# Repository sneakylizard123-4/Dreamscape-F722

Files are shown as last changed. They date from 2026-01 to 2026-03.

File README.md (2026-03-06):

# Dreamscape F722
Dreamscape F722 is an open-hardware STM32-based flight controller designed for FPV and custom drone platforms. It targets high-performance firmware such as Betaflight, iNav, and ArduPilot while remaining developer-friendly for experimentation and customization. The design focuses on a powerful MCU, robust connectivity, and support for a wide range of peripherals to enable advanced flight control features and future expansion.

# Features
## MCU
- STM32 F722RET6
- 32-bit ARM Cortex-M7 CPU
- Up to 216 MHz clock speed
- Large memory for advanced firmware features
- Compatible with Betaflight/iNav/ArduPilot

## Power System
- 5V input with built-in 3.3v regulator
- Power distribution for peripherals
- USB Power support
- Protection for USB

## Connectivity
- USB Type-C for programming and communication
- Multiple UART ports for telemetry and peripherals
- I2C bus for sensors and accessories
- SPI interface for high-speed communication
- SWD debugging port

## Sensors
- ICM-42688-P 6-axis IMU (3-axis gyroscope + 3-axis accelerometer) via SPI for precise flight control and low latency
- BMP280 barometer for altitude sensing
- Optional external sensor support via I2C

## Flight Control Outputs
- 8 PWM outputs
- Supports DSHOT, Oneshot, and standard PWM protocols
- Compatible with individual ESCs or 4-in-1 ESCs

## Radio / Receiver Support
- CRSF (Crossfire) support for long-range control
- SBUS support for standard RC receivers
- PPM support for legacy receivers
- Support for external radio modules via UART

## Status & Indicators
- Power LED
- User LED
- Boot/Status LED

## Expansion & Peripherals
- GPS module support via UART
- Telemetry Radios
- VTX control (SmartAudio or Tramp)
- Buzzer for audible alerts
- Camera control
- External sensor support (e.g., magnetometer, external barometer)

## Physical Design
- Compact flight-controller form factor (30x30mm)
- Standard mounting pattern
- Designed for custom drones

## Development Friendly
- Open-source hardware design files
- Open-source firmware support (Betaflight, iNav, ArduPilot)
- Easy debugging with SWD port

## Planned Future Features
- Integrated ELRS receiver
- Dual-Band telemetry support
- Advanced Sensor suite
- Power monitoring improvements
- Integrated OSD support

# Specifications
## Core Specifications
### MCU
- MCU: STM32 F722RET6
- Architecture: ARM Cortex-M7
- Clock Speed: Up to 216 MHz
- Flash Memory: 512 KB
- RAM: 256 KB
- Hardware Floating Point Unit (FPU)

### Inertial Measurement Unit (IMU)
- IMU: ICM-42688-P
- HIgh-speed SPI bus for low latency
- Optimied placement for reduced vibration noise

### Power System
- Input Voltage: 5V (via USB or power distribution)
- Built-in 3.3V regulator for peripherals
- USB Power support with protection
- Power distribution for connected peripherals

## I/O and Connectivity
### UART Ports
- UART1: Receiver 
- UART2: GPS module
- UART3: Telemetry
- UART4: VTX Control
- UART5: Reserved for future expansion

### SPI Interfaces
- SPI1: IMU (ICM-42688-P)
- SPI2: Reserved for future sensor expansion

### I2C Bus
- I2C bus available for peripherals such as magnetometers, external barometers, etc.

### SWD
- SWD header for debugging and firmware development

## Motor Outputs
- Up to 8 PWM outputs
- Suppored Protocols:
  - DShot150/300/600
  - OneShot
  - Multishot
  - Standard PWM
  - Compatible with individual ESCs or 4-in-1 ESCs

## Receiver Support
- CRSF (Crossfire) support for long-range control
- SBUS support for standard RC receivers
- PPM support for legacy receivers
- Support for external radio modules via UART

## Additional Peripherals
- Buzzer output
- LED Strip output
- Camera control
- VTX control (SmartAudio or Tramp)

## Status Indicators
- Power LED
- User LED
- Boot/Status LED

## Physical Dimensions
- Size: 30x30mm
- Board Layers: 4
- PCB Thickness: 1.6mm
- Copper Weight: 1oz
- Dimensions: Standard flight controller mounting pattern

## Firmware Compatibility
- Designed for compatibility with Betaflight, iNav, and ArduPilot
- Open-source firmware support for customization and development

## Development Features
- Open Hardware design
- Full SWD debugging support
- Compatible with ST-Link Programmers
- Designed for experimentation and customization

## Planned Future Features
- Integrated ELRS receiver for long-range control
- Dual-Band telemetry support for improved communication
- Advanced Sensor suite including magnetometer and external barometer support
- Integrated ESC for AIO support
- Integrated OSD support for on-screen display of flight information
- Improved powwer monitoring with current sensing and voltage monitoring

# Firmware Building
````bash
cd ~/Dreamscape-F722/firmware/betaflight/betaflight
make configs
make DREAMSCAPEF722
````

# Blender Render:
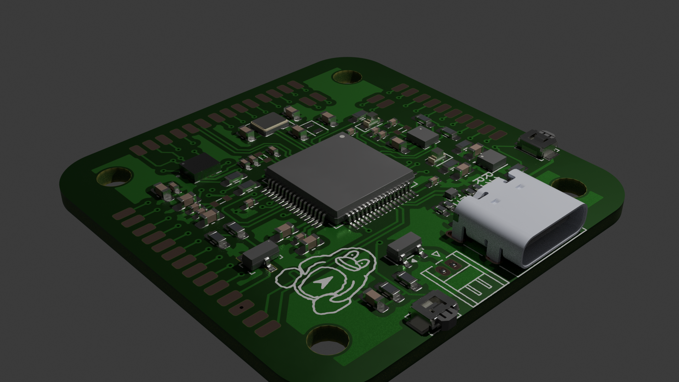
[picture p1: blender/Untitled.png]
BlenderRender

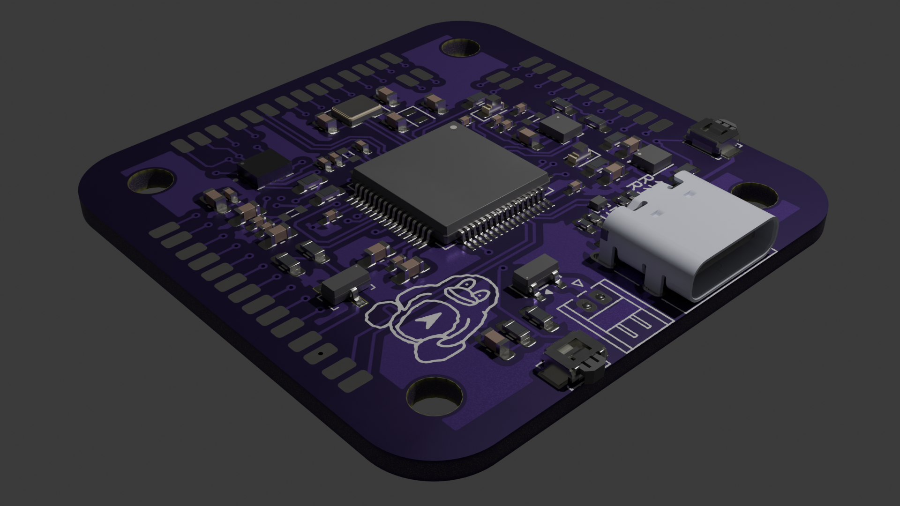
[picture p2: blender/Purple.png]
Purple


# Schematics & PCB view
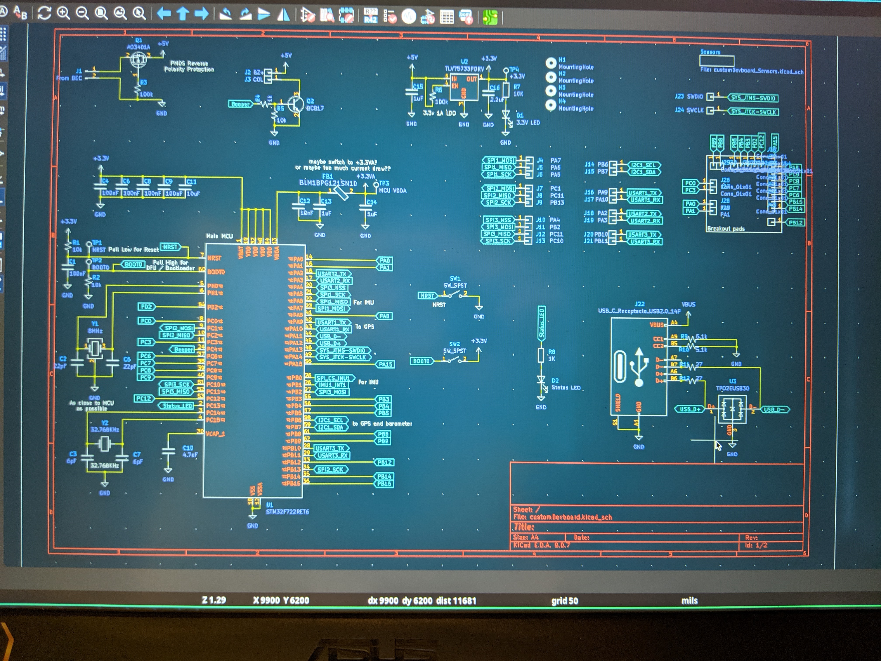
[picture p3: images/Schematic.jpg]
Schematic

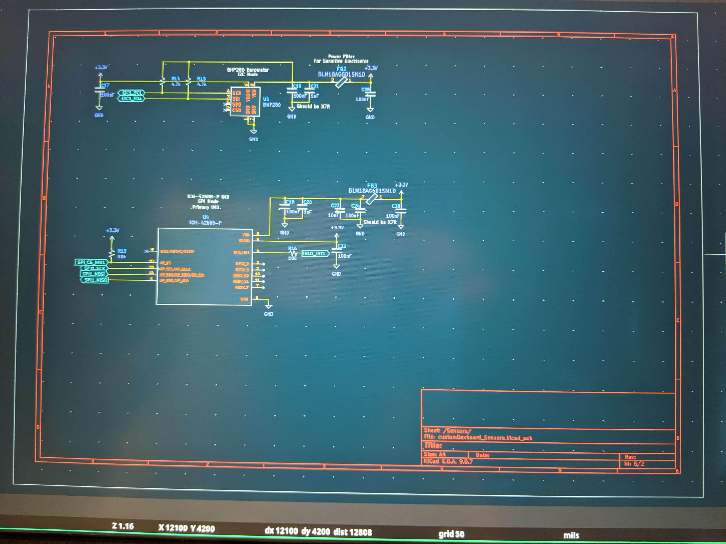
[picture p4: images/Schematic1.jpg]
Schematic1

PCB
PDF

# prices
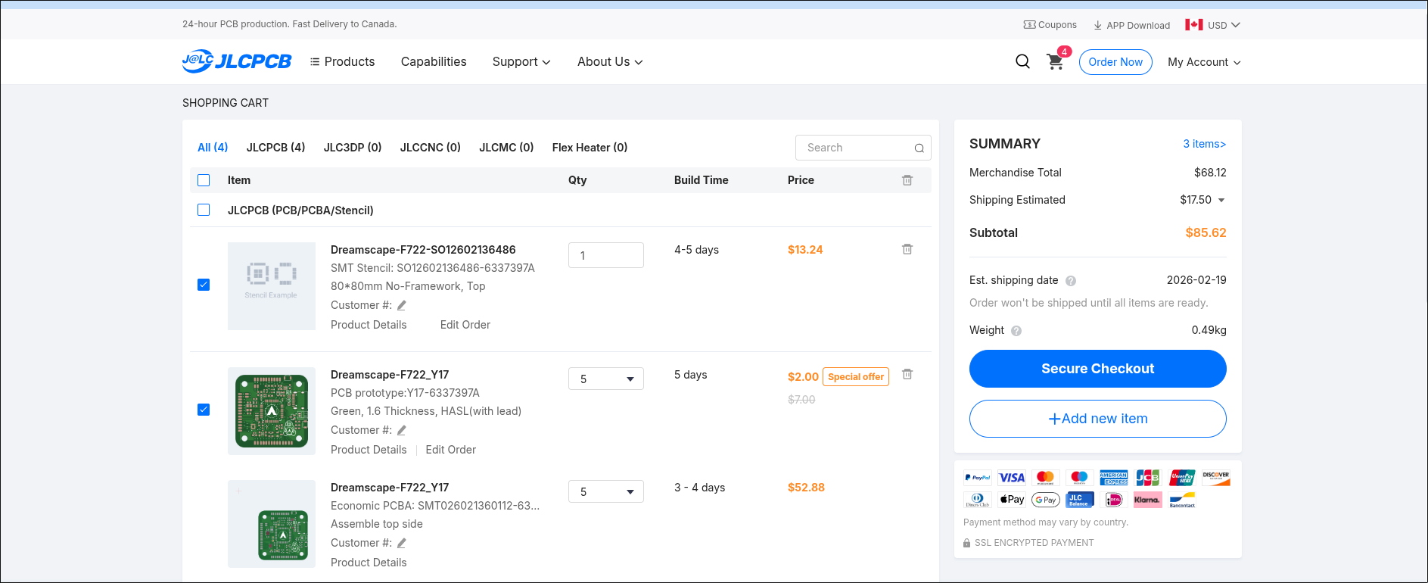
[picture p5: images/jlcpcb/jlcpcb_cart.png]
Cart

# LCSC (Hand Soldering)
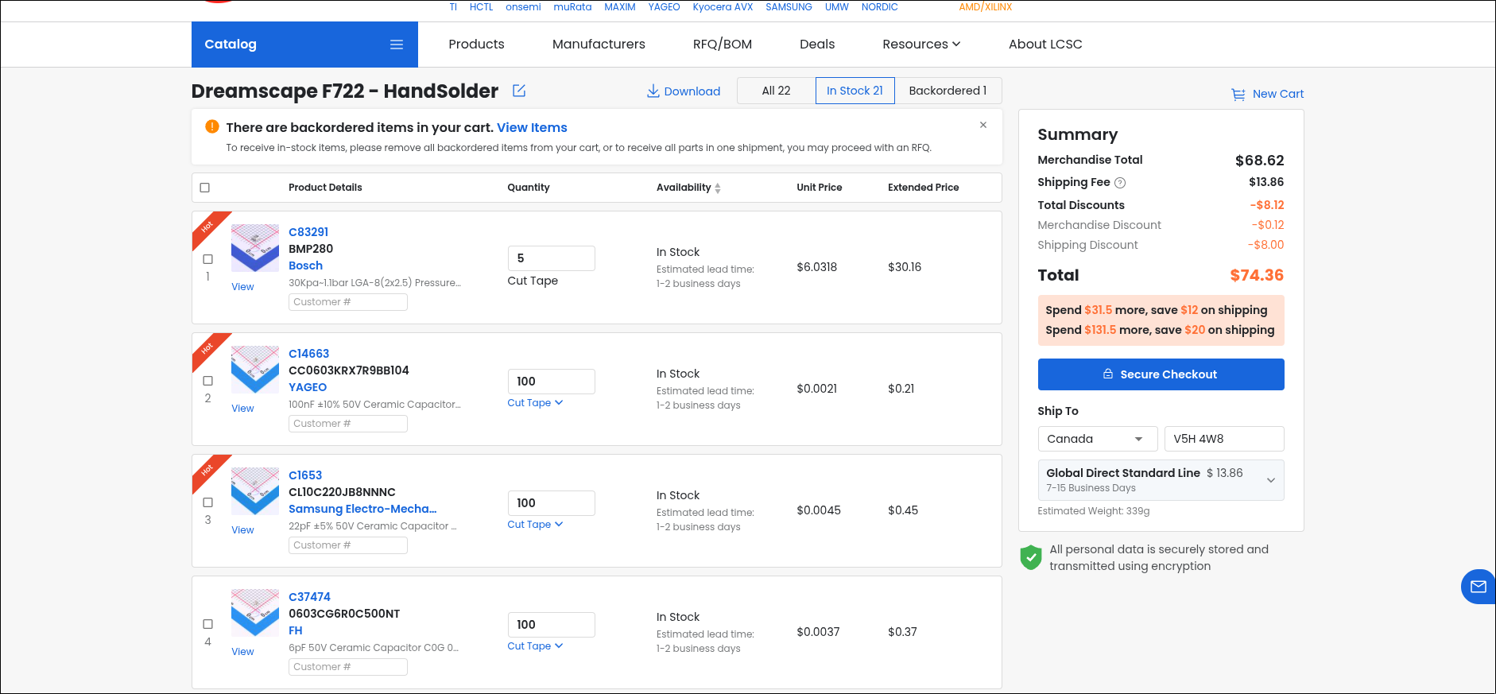
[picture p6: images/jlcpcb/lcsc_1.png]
LCSC1

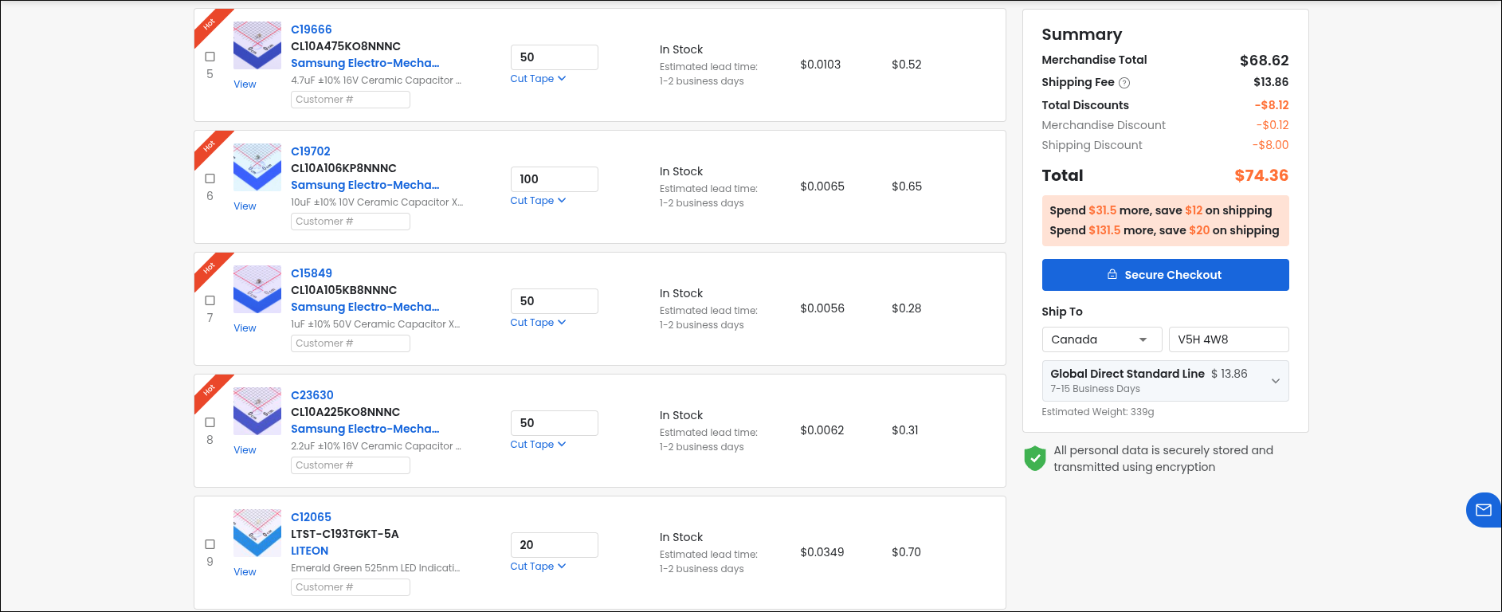
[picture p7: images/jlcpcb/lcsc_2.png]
LCSC2

LCSC3
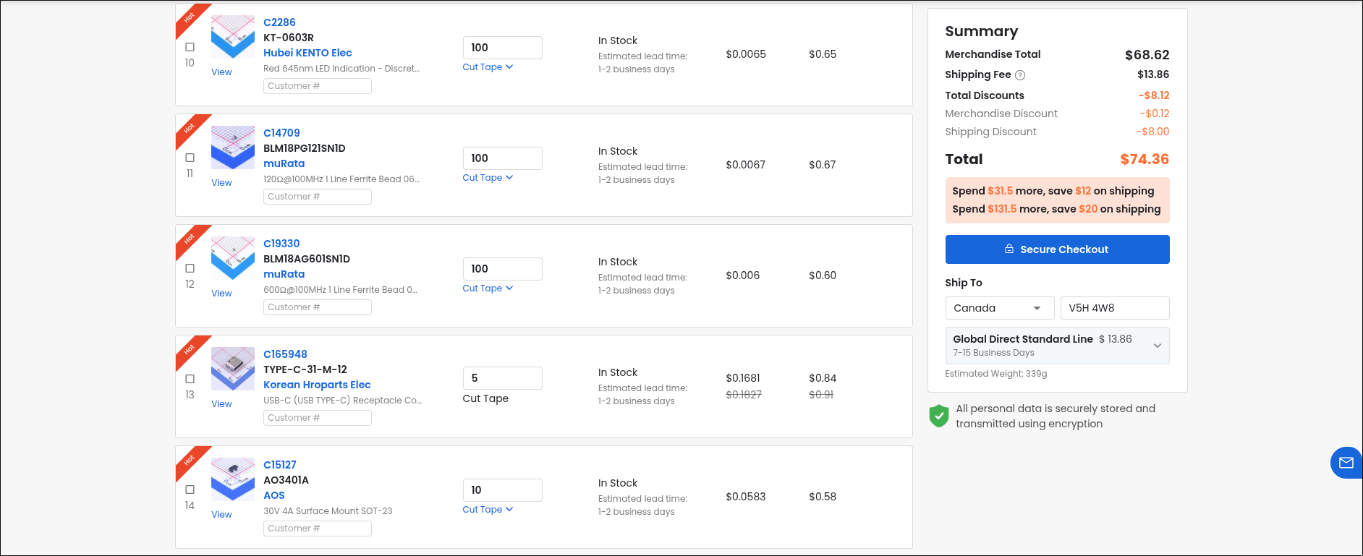
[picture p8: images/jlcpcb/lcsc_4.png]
LCSC4

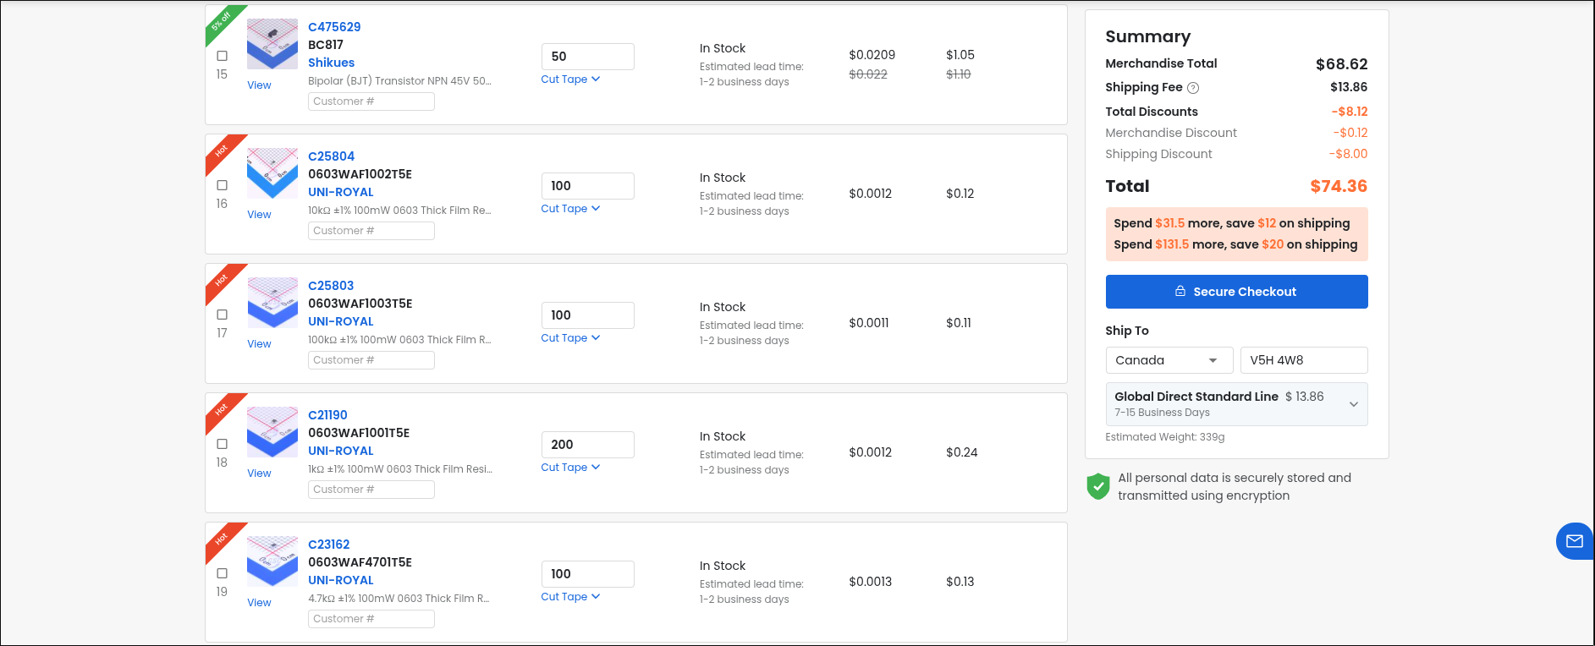
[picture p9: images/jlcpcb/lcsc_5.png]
LCSC5

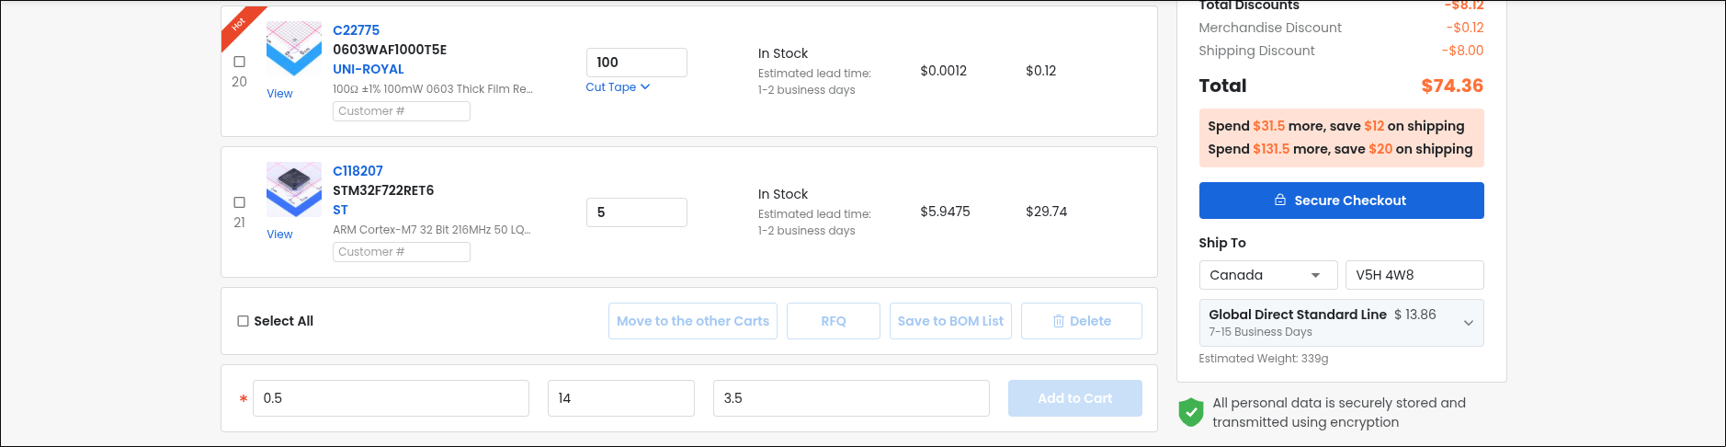
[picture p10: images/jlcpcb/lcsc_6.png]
LCSC6


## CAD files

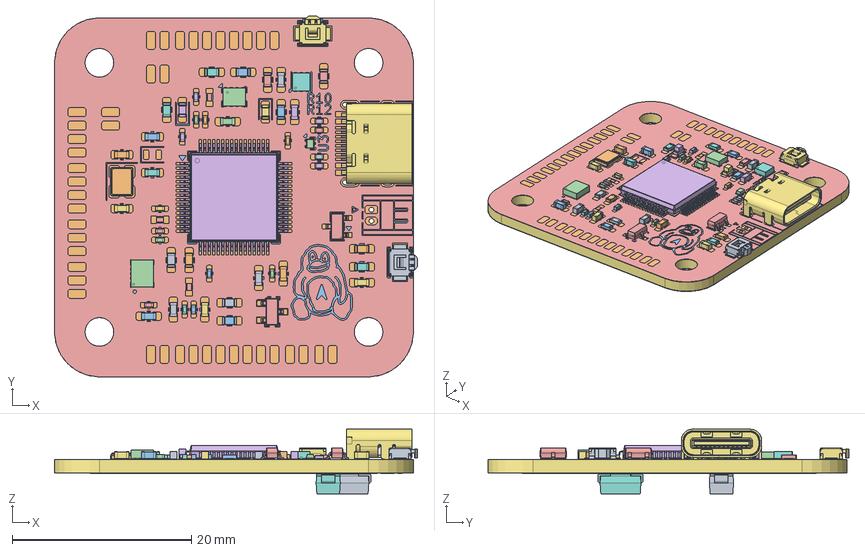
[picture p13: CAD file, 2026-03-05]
cad/Unnamed.FCStd
40.5 x 40.2 x 7.21 mm
C_0603_1608Metric
C_0603_1608Metric001
C_0603_1608Metric002
ICM-42688-P
R_0402_1005Metric
LQFP-64_10x10mm_P0.5mm
C_0603_1608Metric003
R_0603_1608Metric
R_0603_1608Metric001
C_0402_1005Metric
R_0603_1608Metric002
C_0402_1005Metric001
C_0402_1005Metric002
C_0402_1005Metric003
C_0603_1608Metric004
C_0402_1005Metric004
C_0603_1608Metric005
Crystal_SMD_3225-4Pin_3.2x2.5mm
R_0603_1608Metric003
Bosch_LGA-8_2x2.5mm_P0.65mm_ClockwisePinNumbering
R_0603_1608Metric004
R_0402_1005Metric001
LED_0603_1608Metric
R_0603_1608Metric005
C_0603_1608Metric006
R_0603_1608Metric006
R_0603_1608Metric007
C_0402_1005Metric005
R_0603_1608Metric008
R_0402_1005Metric002
SW_SPST_B3U-3000P
WSON-6-1EP_2x2mm_P0.65mm_EP1x1.6mm
R_0603_1608Metric009
C_0402_1005Metric006
C_0603_1608Metric007
C_0603_1608Metric008
C_0402_1005Metric007
C_0603_1608Metric009
TYPE-C-31-M-12
R_0603_1608Metric010
SW_SPST_B3U-3000P001
C_0603_1608Metric010
C_0402_1005Metric008
C_0402_1005Metric009
SOT-23
LED_0603_1608Metric001
C_0402_1005Metric010
C_0603_1608Metric011
R_0402_1005Metric003
R_0603_1608Metric011
C_0402_1005Metric011
Texas_DRT-3
SOT-024
C_0402_1005Metric012
C_0603_1608Metric012
D_SMA
D_SMA001
Dreamscape-F722_copper
Dreamscape-F722_silkscreen
Dreamscape-F722_silkscreen001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

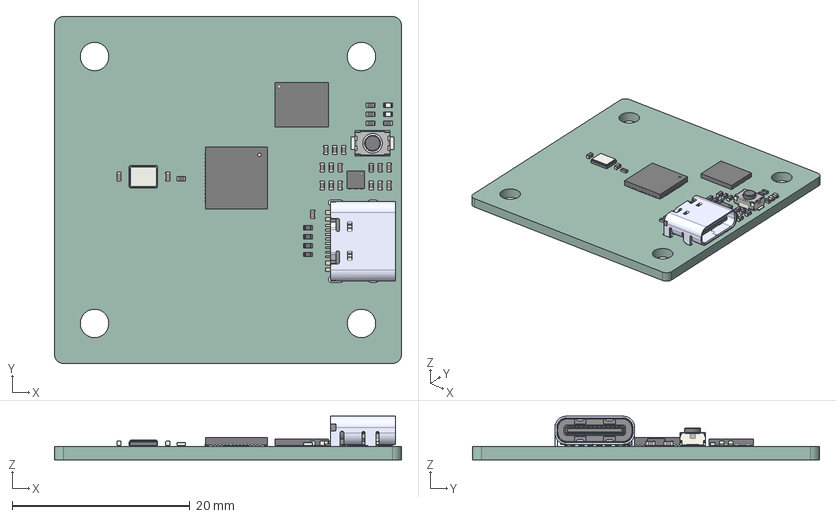
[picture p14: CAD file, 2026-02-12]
kicad/Dreamscape-F722.step
39.0 x 39.0 x 4.91 mm
WSON-8-1EP_6x5mm_P1.27mm_EP3.4x4.3mm
C_0402_1005Metric x 18
R_0402_1005Metric x 9
SW_Push_SPST_NO_Alps_SKRK
LED_0402_1005Metric x 2
QFN-56-1EP_7x7mm_P0.4mm_EP3.2x3.2mm
WSON-6-1EP_2x2mm_P0.65mm_EP1x1.6mm
TYPE-C-31-M-12
Crystal_SMD_3225-4Pin_3.2x2.5mm
customDevboard_PCB

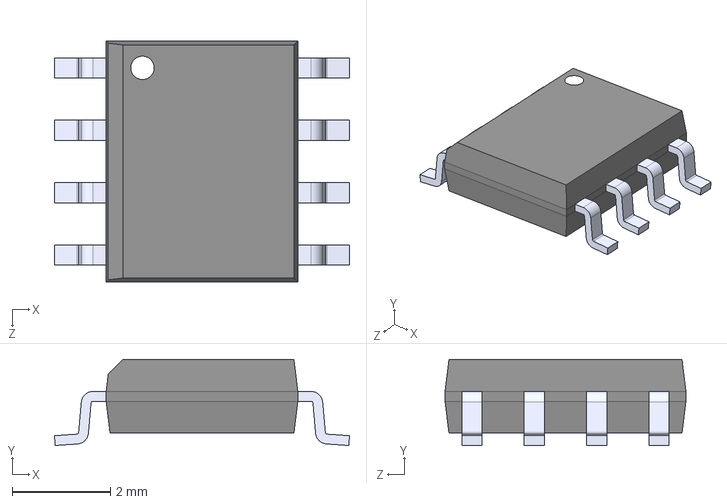
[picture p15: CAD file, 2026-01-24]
kicad/ImportedParts/AO4435/AO4435.step
6.00 x 1.75 x 4.90 mm

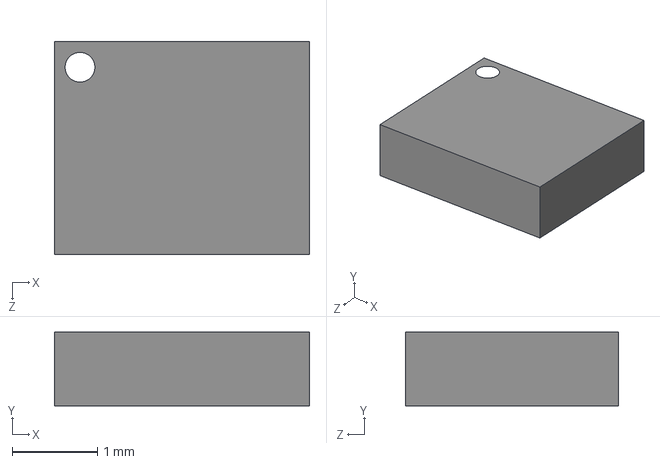
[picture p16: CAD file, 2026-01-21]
kicad/ImportedParts/BMI270/BMI270.step
3.00 x 0.87 x 2.50 mm

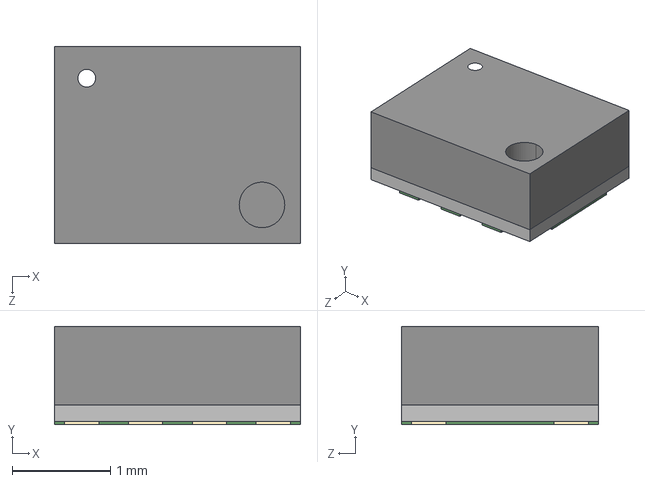
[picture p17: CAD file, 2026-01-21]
kicad/ImportedParts/DPS310/DPS310.step
2.50 x 1.00 x 2.00 mm

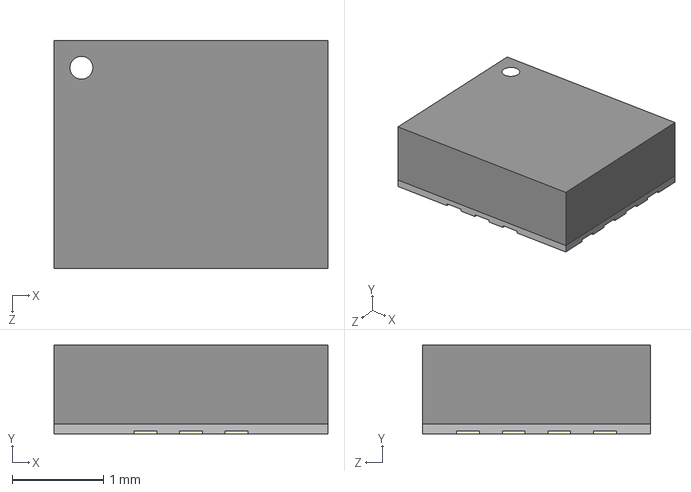
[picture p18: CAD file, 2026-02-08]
kicad/ImportedParts/ICM_42688_P/ICM-42688-P.step
3.00 x 0.97 x 2.50 mm

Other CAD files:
blender/Dreamscape-F722.blend

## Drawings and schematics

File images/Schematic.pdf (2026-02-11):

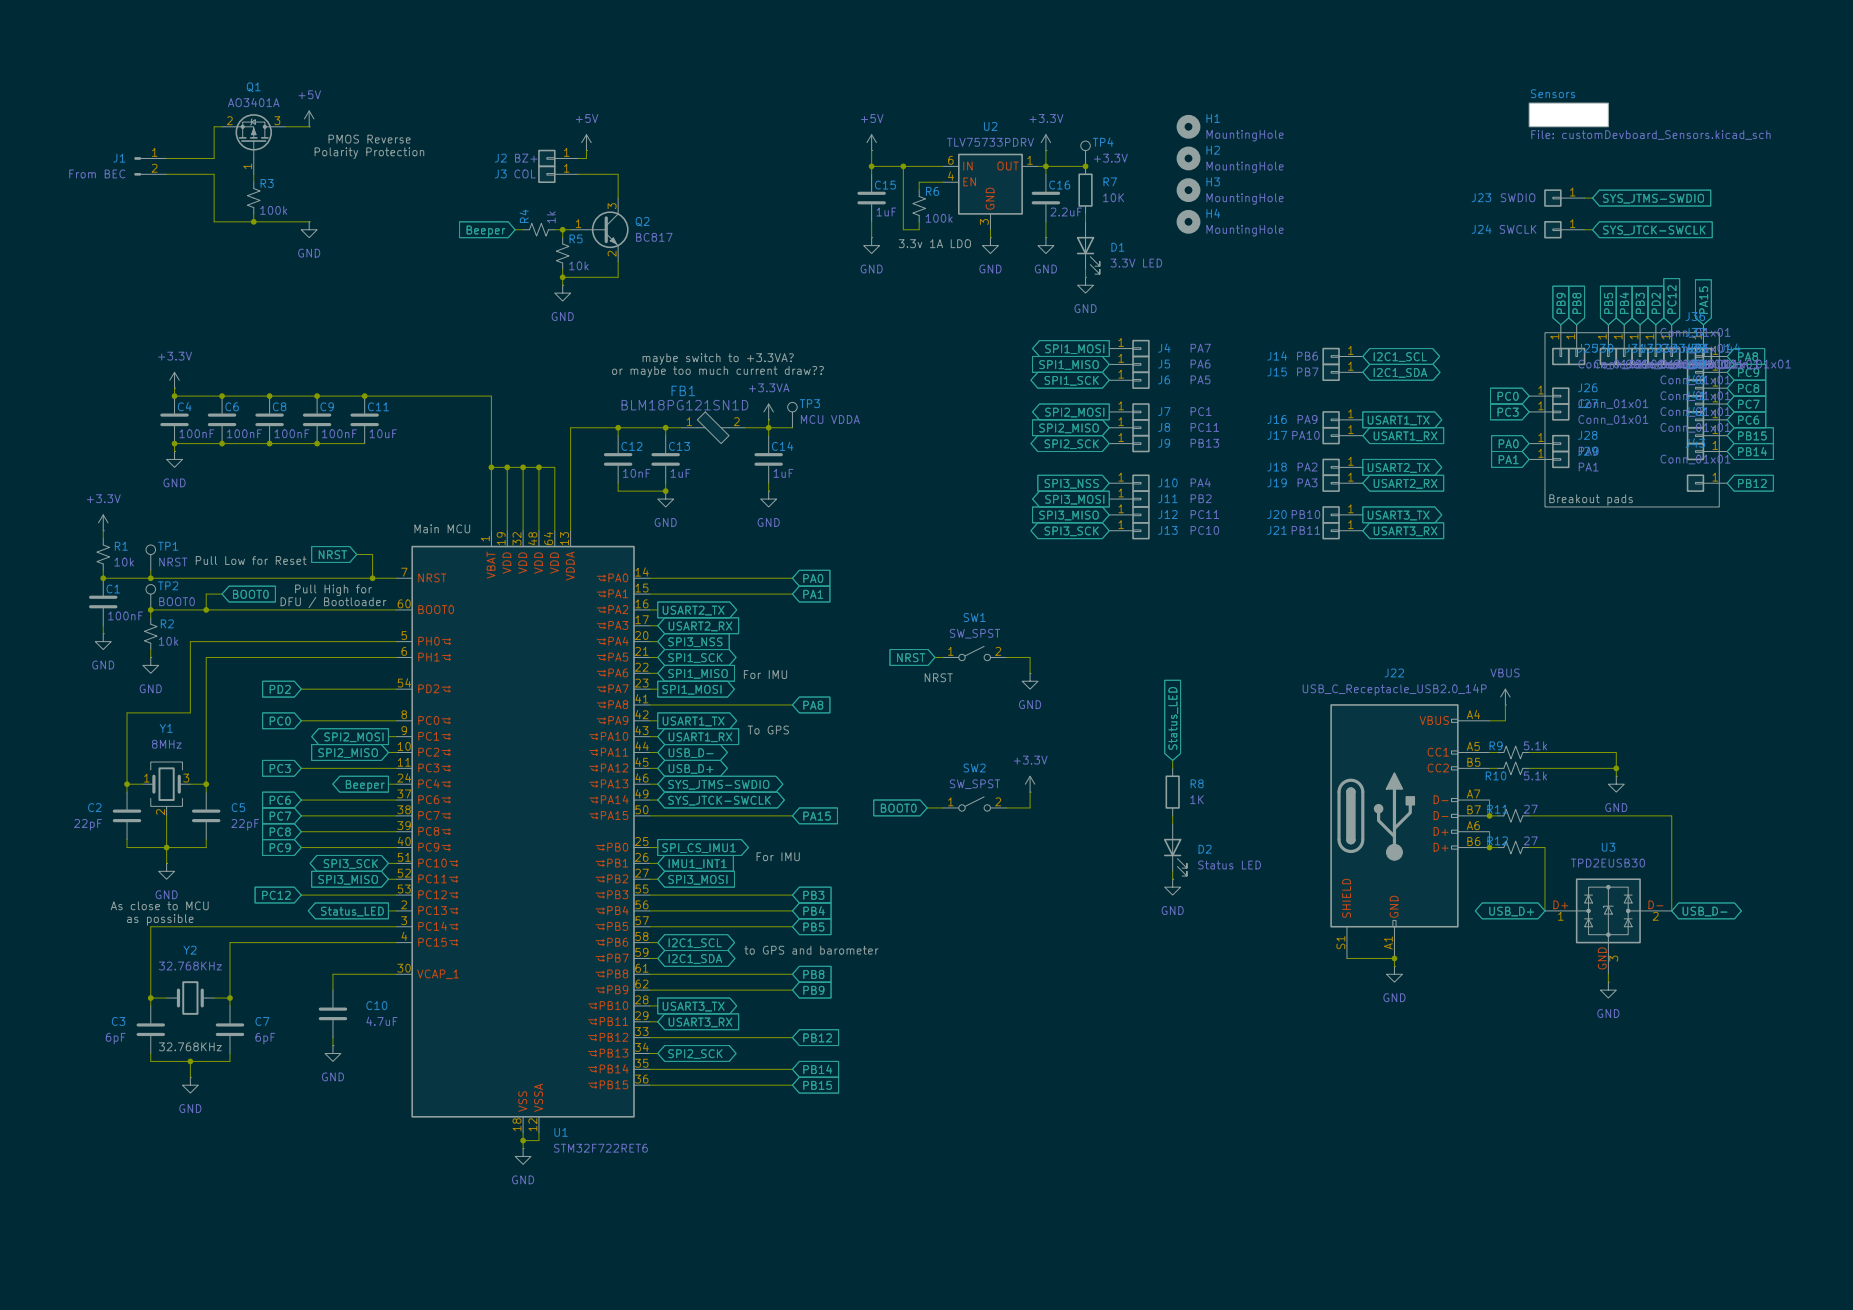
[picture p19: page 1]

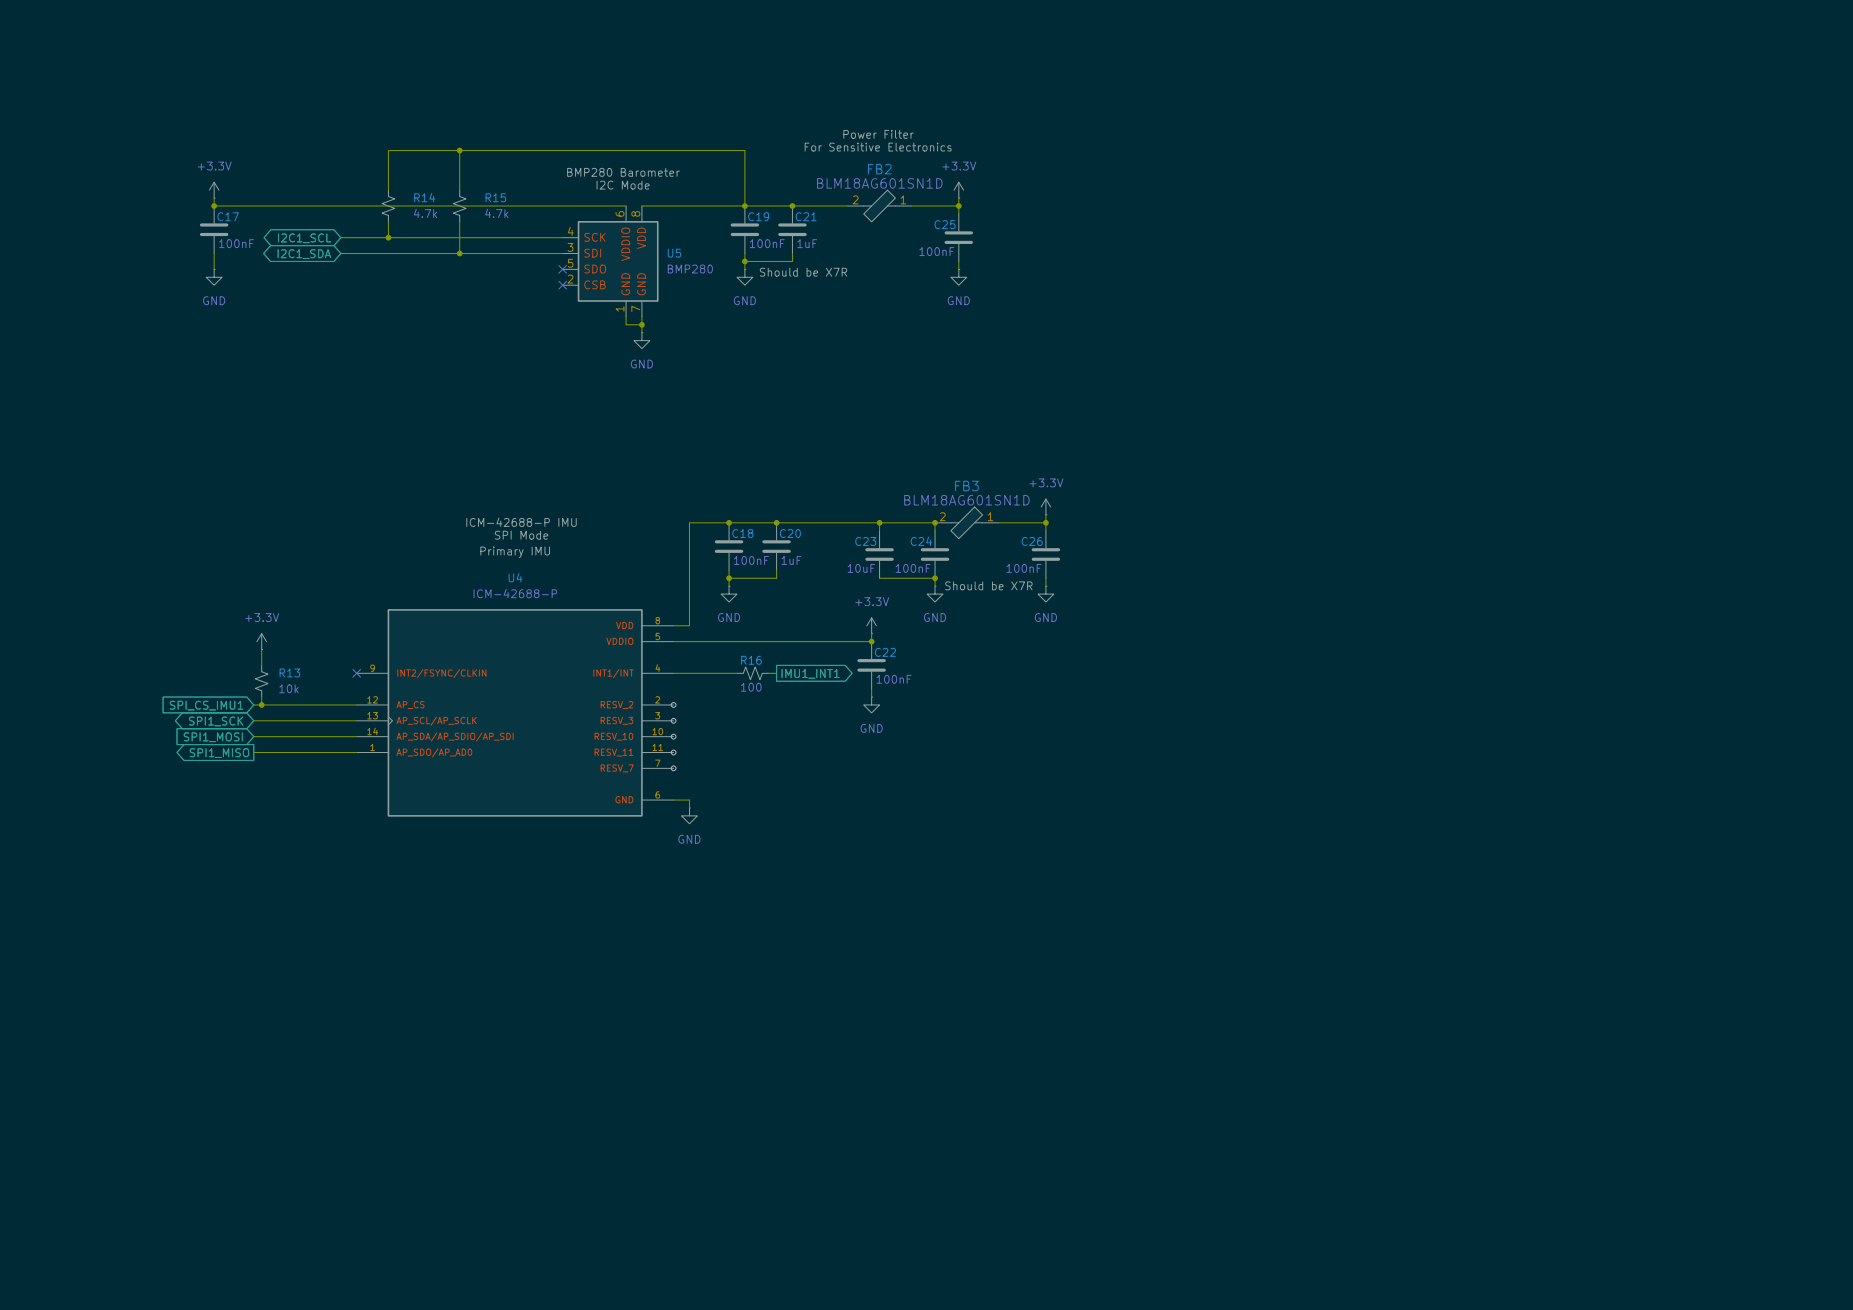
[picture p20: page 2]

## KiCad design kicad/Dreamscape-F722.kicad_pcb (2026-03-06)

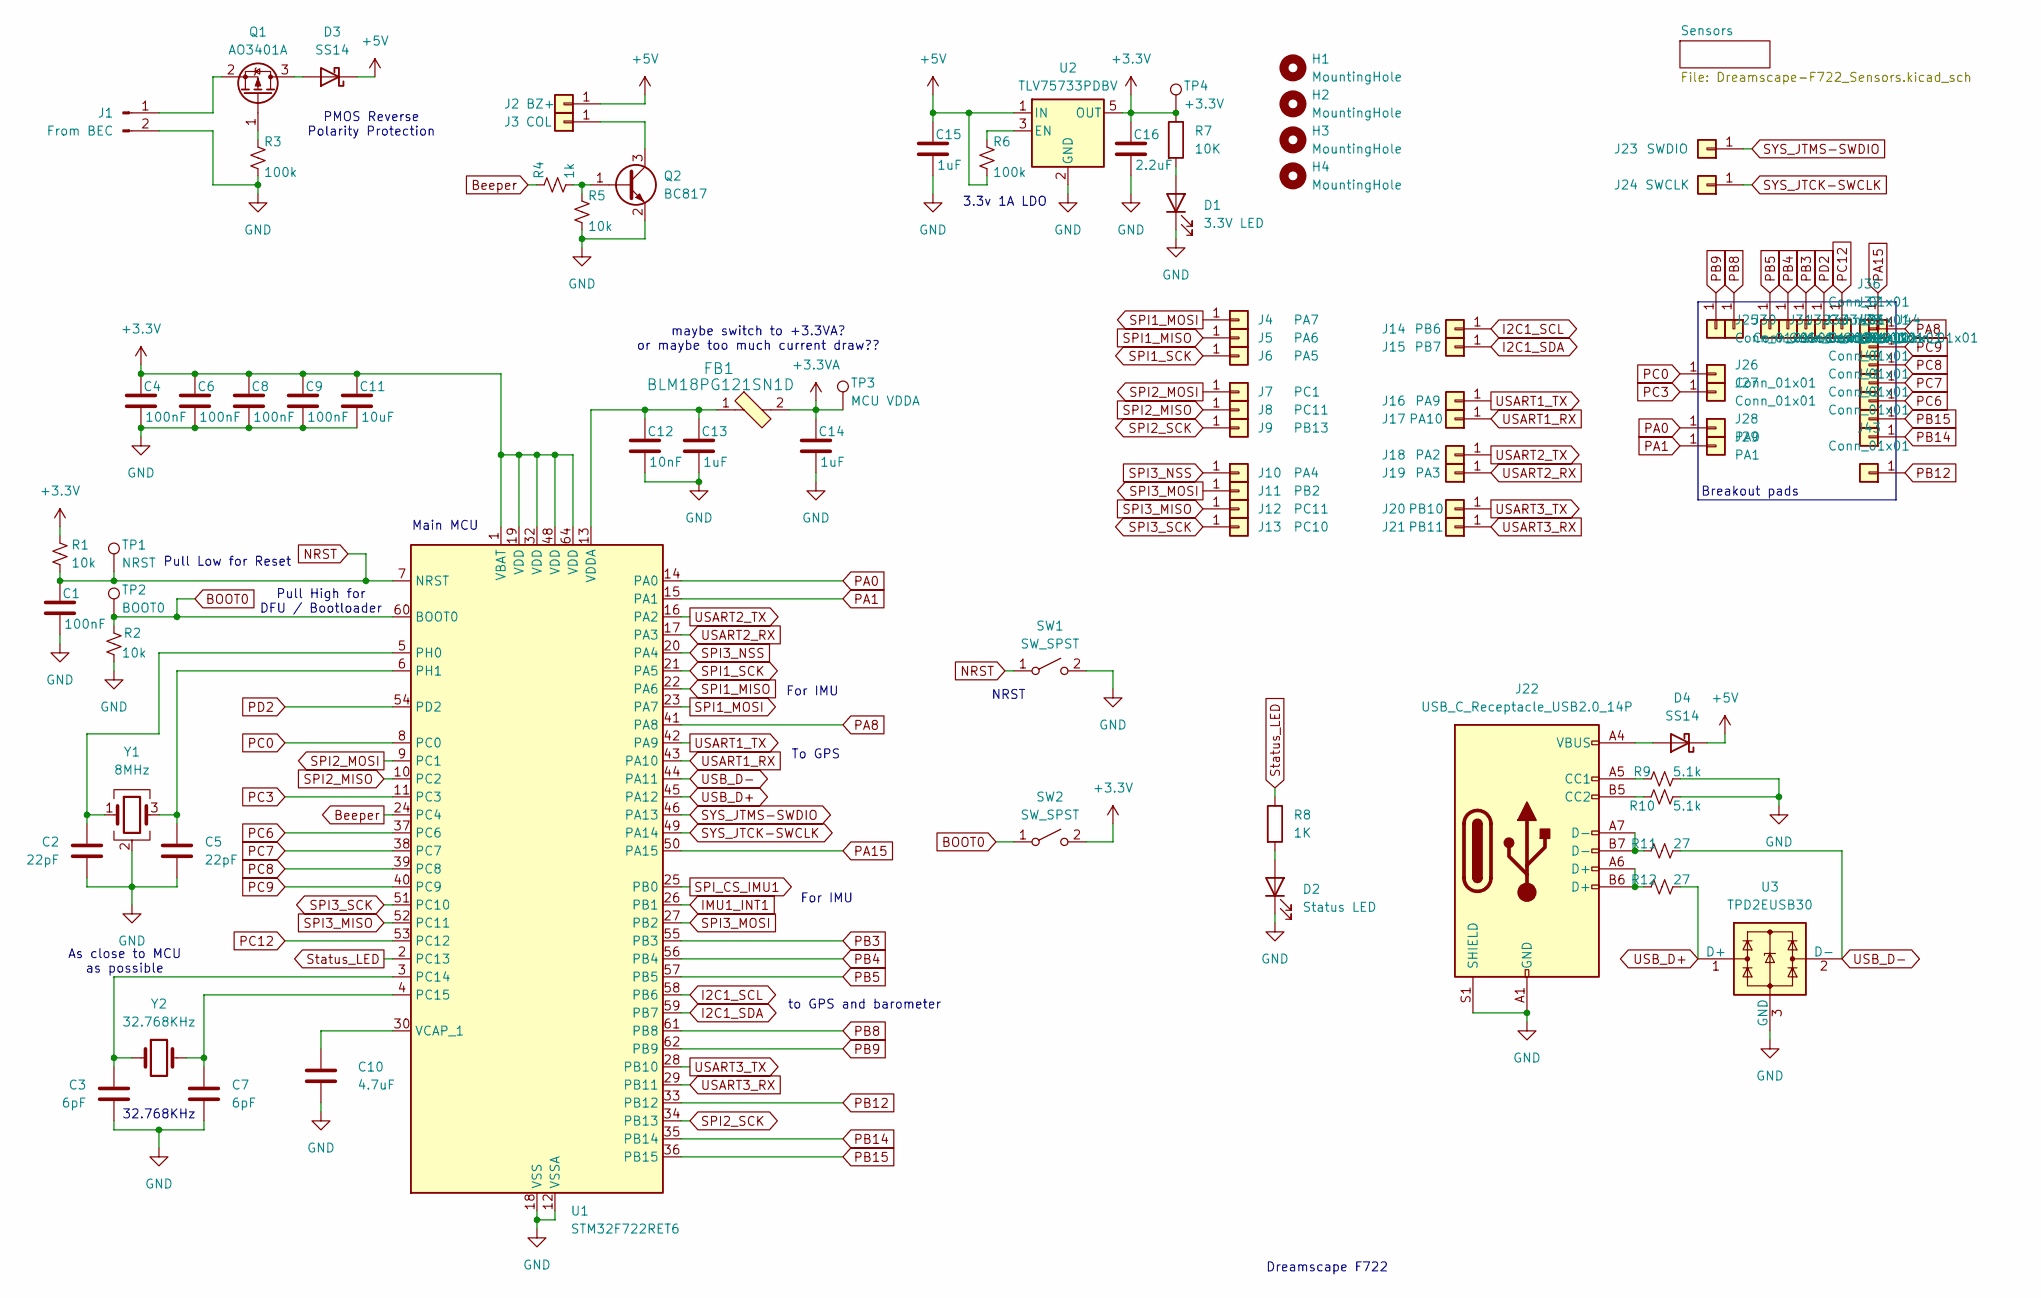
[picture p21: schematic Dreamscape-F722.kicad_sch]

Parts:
C1: 100nF; C_0603_1608Metric_Pad1.08x0.95mm_HandSolder
C2, C5: 22pF; C_0603_1608Metric
C3, C7: 6pF; C_0603_1608Metric
C4, C6, C8, C9: 100nF; C_0402_1005Metric_Pad0.74x0.62mm_HandSolder
C10: 4.7uF; C_0603_1608Metric_Pad1.08x0.95mm_HandSolder
C11: 10uF; C_0603_1608Metric_Pad1.08x0.95mm_HandSolder
C12: 10nF; C_0402_1005Metric_Pad0.74x0.62mm_HandSolder
C13, C14: 1uF; C_0402_1005Metric_Pad0.74x0.62mm_HandSolder
C15: 1uF; C_0603_1608Metric_Pad1.08x0.95mm_HandSolder
C16: 2.2uF; C_0603_1608Metric_Pad1.08x0.95mm_HandSolder
D1: 3.3V LED; LED_0603_1608Metric
D2: Status LED; LED_0603_1608Metric_Pad1.05x0.95mm_HandSolder
D3, D4: SS14; D_SMA
FB1: BLM18PG121SN1D; 0603; MPN BLM18PG121SN1D; Digi-Key_PN 490-1037-1-ND
H1, H2, H3, H4: MountingHole; MountingHole_3.2mm_M3
J1: From BEC; Hirose_DF13-02P-1.25DS_1x02_P1.25mm_Horizontal
J2: BZ+; SolderWirePad_1x01_SMD_1x2mm
J3: COL; SolderWirePad_1x01_SMD_1x2mm
J4: PA7; SolderWirePad_1x01_SMD_1x2mm
J5: PA6; SolderWirePad_1x01_SMD_1x2mm
J6: PA5; SolderWirePad_1x01_SMD_1x2mm
J7: PC1; SolderWirePad_1x01_SMD_1x2mm
J8, J12: PC11; SolderWirePad_1x01_SMD_1x2mm
J9: PB13; SolderWirePad_1x01_SMD_1x2mm
J10: PA4; SolderWirePad_1x01_SMD_1x2mm
J11: PB2; SolderWirePad_1x01_SMD_1x2mm
J13: PC10; SolderWirePad_1x01_SMD_1x2mm
J14: PB6; SolderWirePad_1x01_SMD_1x2mm
J15: PB7; SolderWirePad_1x01_SMD_1x2mm
J16: PA9; SolderWirePad_1x01_SMD_1x2mm
J17: PA10; SolderWirePad_1x01_SMD_1x2mm
J18: PA2; SolderWirePad_1x01_SMD_1x2mm
J19: PA3; SolderWirePad_1x01_SMD_1x2mm
J20: PB10; SolderWirePad_1x01_SMD_1x2mm
J21: PB11; SolderWirePad_1x01_SMD_1x2mm
J22: USB_C_Receptacle_USB2.0_14P; USB_C_Receptacle_HRO_TYPE-C-31-M-12
J23: SWDIO; SolderWirePad_1x01_SMD_1x2mm
J24: SWCLK; SolderWirePad_1x01_SMD_1x2mm
J25, J26, J27, J30, J31, J32, J33, J34, J35, J36, J37, J38, J39, J40, J41, J42, J43, J44: Conn_01x01; SolderWirePad_1x01_SMD_1x2mm
J28: PA0; SolderWirePad_1x01_SMD_1x2mm
J29: PA1; SolderWirePad_1x01_SMD_1x2mm
Q1: AO3401A; SOT-23
Q2: BC817; SOT-23-3
R1, R2, R5: 10k; R_0603_1608Metric_Pad0.98x0.95mm_HandSolder
R3, R6: 100k; R_0603_1608Metric_Pad0.98x0.95mm_HandSolder
R4: 1k; R_0603_1608Metric_Pad0.98x0.95mm_HandSolder
R7: 10K; R_0603_1608Metric_Pad0.98x0.95mm_HandSolder
R8: 1K; R_0603_1608Metric_Pad0.98x0.95mm_HandSolder
R9, R10: 5.1k; R_0402_1005Metric_Pad0.72x0.64mm_HandSolder
R11, R12: 27; R_0402_1005Metric_Pad0.72x0.64mm_HandSolder
SW1, SW2: SW_SPST; SW_SPST_B3U-3000P
TP1: NRST; TestPoint_Pad_1.0x1.0mm
TP2: BOOT0; TestPoint_Pad_1.0x1.0mm
TP3: MCU VDDA; TestPoint_Pad_1.0x1.0mm
TP4: +3.3V; TestPoint_Pad_1.0x1.0mm
U1: STM32F722RET6; LQFP-64_10x10mm_P0.5mm
U2: TLV75733PDBV; SOT-23-5
U3: TPD2EUSB30; Texas_DRT-3
Y1: 8MHz; Crystal_SMD_3225-4Pin_3.2x2.5mm; LCSC C2905353
Y2: 32.768KHz; Crystal_SMD_2012-2Pin_2.0x1.2mm; LCSC C99009

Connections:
+3.3V: C4.1, C6.1, C8.1, C9.1, C11.1, C16.1, R1.1, R7.1, SW2.2 (B), TP4.1, U1.1 (VBAT), U1.19 (VDD), U1.32 (VDD), U1.48 (VDD), U1.64 (VDD), U2.5 (OUT); also elsewhere on the board
+3.3VA: C14.1, FB1.2, TP3.1
+5V: C15.1, D3.1 (K), D4.1 (K), J2.1, R6.2, U2.1 (IN)
BOOT0: R2.1, SW2.1 (A), TP2.1, U1.60 (BOOT0)
Beeper: R4.1, U1.24 (PC4)
GND: C1.2, C2.2, C3.2, C4.2, C5.2, C6.2, C7.2, C8.2, C9.2, C10.2, C11.2, C12.2, C13.2, C14.2, C15.2, C16.2, D1.1 (K), D2.1 (K), J1.2, J22.A1 (GND), J22.A12 (GND), J22.B1 (GND), J22.B12 (GND), J22.S1 (SHIELD), Q2.2 (E), R2.2, R3.2, R5.2, R9.2, R10.1, SW1.2 (B), U1.12 (VSSA), U1.18 (VSS), U1.31 (VSS), U1.47 (VSS), U1.63 (VSS), U2.2 (GND), U3.3 (GND), Y1.2 (G), Y1.4 (G); also elsewhere on the board
I2C1_SCL: J14.1, U1.58 (PB6); also elsewhere on the board
I2C1_SDA: J15.1, U1.59 (PB7); also elsewhere on the board
IMU1_INT1: U1.26 (PB1); also elsewhere on the board
NRST: C1.1, R1.2, SW1.1 (A), TP1.1, U1.7 (NRST)
unnamed: D1.2 (A), R7.2
unnamed: D2.2 (A), R8.2
unnamed: D3.2 (A), Q1.3 (D)
unnamed: D4.2 (A), J22.A4 (VBUS), J22.A9 (VBUS), J22.B4 (VBUS), J22.B9 (VBUS)
unnamed: J1.1, Q1.2 (S)
unnamed: J3.1, Q2.3 (C)
unnamed: J22.A5 (CC1), R9.1
unnamed: J22.B5 (CC2), R10.2
unnamed: J22.A6 (D+), J22.B6 (D+), R12.2
unnamed: J22.A7 (D-), J22.B7 (D-), R11.1
unnamed: Q1.1 (G), R3.1
unnamed: Q2.1 (B), R4.2, R5.1
unnamed: C3.1, U1.3 (PC14), Y2.1
unnamed: C7.1, U1.4 (PC15), Y2.2
unnamed: C2.1, U1.5 (PH0), Y1.1
unnamed: C5.1, U1.6 (PH1), Y1.3
unnamed: C10.1, U1.30 (VCAP_1)
unnamed: C12.1, C13.1, FB1.1, U1.13 (VDDA)
unnamed: R6.1, U2.3 (EN)
PA0: J28.1, U1.14 (PA0)
PA1: J29.1, U1.15 (PA1)
PA8: J36.1, U1.41 (PA8)
PA15: J44.1, U1.50 (PA15)
PB3: J33.1, U1.55 (PB3)
PB4: J32.1, U1.56 (PB4)
PB5: J31.1, U1.57 (PB5)
PB8: J30.1, U1.61 (PB8)
PB9: J25.1, U1.62 (PB9)
PB12: J43.1, U1.33 (PB12)
PB14: J42.1, U1.35 (PB14)
PB15: J41.1, U1.36 (PB15)
PC0: J26.1, U1.8 (PC0)
PC3: J27.1, U1.11 (PC3)
PC6: J40.1, U1.37 (PC6)
PC7: J39.1, U1.38 (PC7)
PC8: J38.1, U1.39 (PC8)
PC9: J37.1, U1.40 (PC9)
PC12: J35.1, U1.53 (PC12)
PD2: J34.1, U1.54 (PD2)
SPI1_MISO: J5.1, U1.22 (PA6); also elsewhere on the board
SPI1_MOSI: J4.1, U1.23 (PA7); also elsewhere on the board
SPI1_SCK: J6.1, U1.21 (PA5); also elsewhere on the board
SPI2_MISO: J8.1, U1.10 (PC2)
SPI2_MOSI: J7.1, U1.9 (PC1)
SPI2_SCK: J9.1, U1.34 (PB13)
SPI3_MISO: J12.1, U1.52 (PC11)
SPI3_MOSI: J11.1, U1.27 (PB2)
SPI3_NSS: J10.1, U1.20 (PA4)
SPI3_SCK: J13.1, U1.51 (PC10)
SPI_CS_IMU1: U1.25 (PB0); also elsewhere on the board
SYS_JTCK-SWCLK: J24.1, U1.49 (PA14)
SYS_JTMS-SWDIO: J23.1, U1.46 (PA13)
Status_LED: R8.1, U1.2 (PC13)
USART1_RX: J17.1, U1.43 (PA10)
USART1_TX: J16.1, U1.42 (PA9)
USART2_RX: J19.1, U1.17 (PA3)
USART2_TX: J18.1, U1.16 (PA2)
USART3_RX: J21.1, U1.29 (PB11)
USART3_TX: J20.1, U1.28 (PB10)
USB_D+: R12.1, U1.45 (PA12), U3.1 (D+)
USB_D-: R11.2, U1.44 (PA11), U3.2 (D-)

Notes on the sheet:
Breakout pads
3.3v 1A LDO
PMOS Reverse Polarity Protection
To GPS
maybe switch to +3.3VA? or maybe too much current draw??
Dreamscape F722
Pull High for DFU / Bootloader
32.768KHz
As close to MCU as possible
to GPS and barometer
For IMU
Pull Low for Reset
Main MCU
NRST

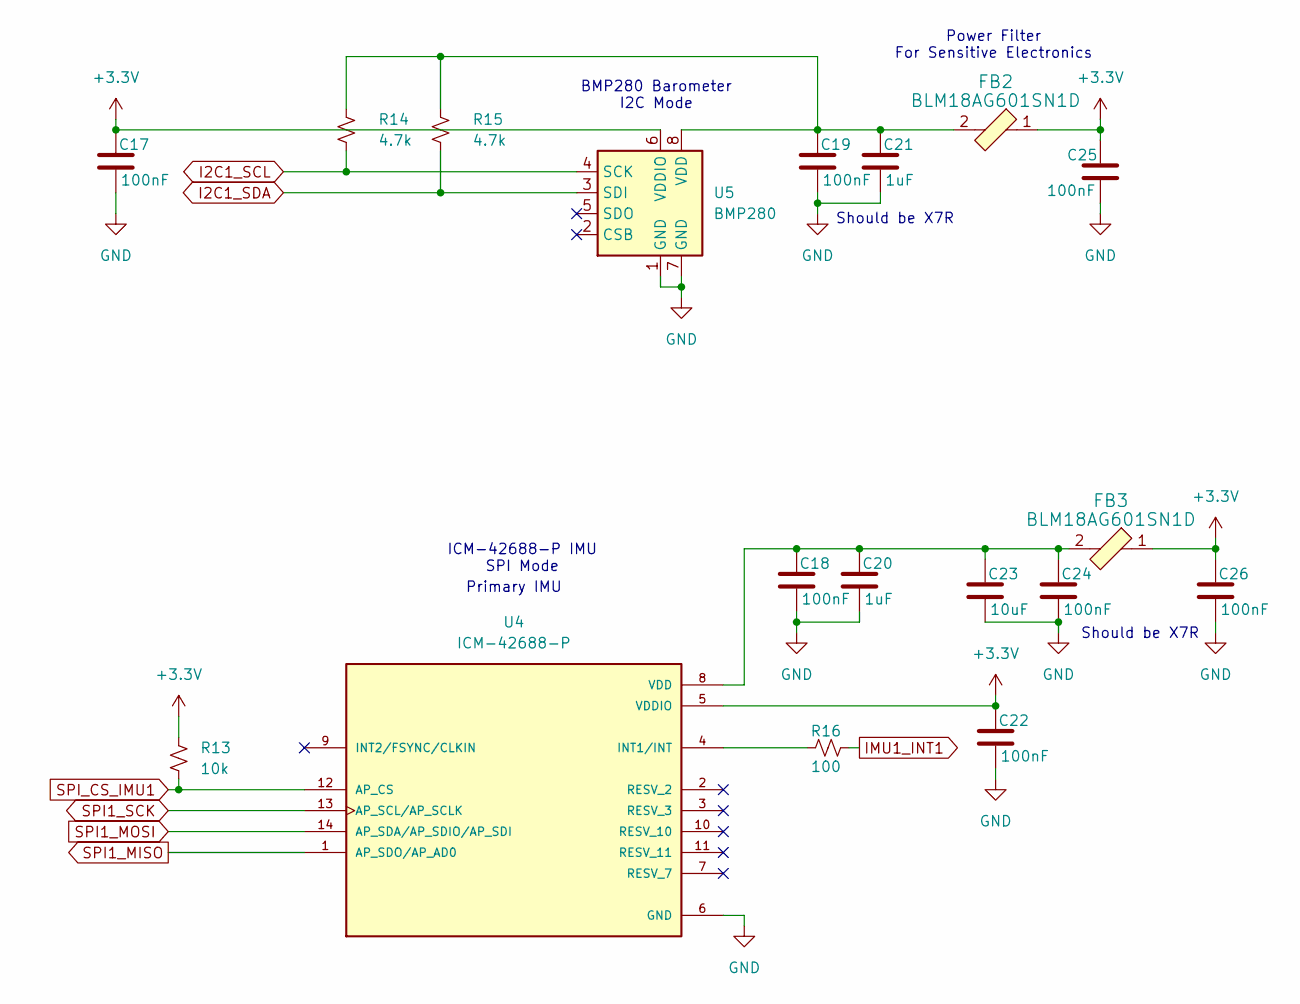
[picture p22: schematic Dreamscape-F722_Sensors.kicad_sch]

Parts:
C17, C18, C19, C22: 100nF; C_0402_1005Metric_Pad0.74x0.62mm_HandSolder
C20, C21: 1uF; C_0402_1005Metric_Pad0.74x0.62mm_HandSolder
C23: 10uF; C_0603_1608Metric_Pad1.08x0.95mm_HandSolder
C24, C25, C26: 100nF; C_0603_1608Metric_Pad1.08x0.95mm_HandSolder
FB2, FB3: BLM18AG601SN1D; 0603; MPN BLM18AG601SN1D; Digi-Key_PN 490-1014-1-ND
R13: 10k; R_0603_1608Metric_Pad0.98x0.95mm_HandSolder
R14, R15: 4.7k; R_0603_1608Metric_Pad0.98x0.95mm_HandSolder
R16: 100; R_0603_1608Metric_Pad0.98x0.95mm_HandSolder
U4: ICM-42688-P; PQFN50P300X250X97-14N; PARTREV 1.2
U5: BMP280; Bosch_LGA-8_2x2.5mm_P0.65mm_ClockwisePinNumbering

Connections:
+3.3V: C17.1, C22.1, C25.1, C26.1, FB2.1, FB3.1, R13.2, U4.5 (VDDIO), U5.6 (VDDIO); also elsewhere on the board
GND: C17.2, C18.2, C19.2, C20.2, C21.2, C22.2, C23.2, C24.2, C25.2, C26.2, U4.6 (GND), U5.1 (GND), U5.7 (GND); also elsewhere on the board
I2C1_SCL: R14.2, U5.4 (SCK); also elsewhere on the board
I2C1_SDA: R15.2, U5.3 (SDI); also elsewhere on the board
IMU1_INT1: R16.2; also elsewhere on the board
unnamed: R16.1, U4.4 (INT1/INT)
unnamed: C18.1, C20.1, C23.1, C24.1, FB3.2, U4.8 (VDD)
unnamed: C19.1, C21.1, FB2.2, R14.1, R15.1, U5.8 (VDD)
SPI1_MISO: U4.1 (AP_SDO/AP_AD0); also elsewhere on the board
SPI1_MOSI: U4.14 (AP_SDA/AP_SDIO/AP_SDI); also elsewhere on the board
SPI1_SCK: U4.13 (AP_SCL/AP_SCLK); also elsewhere on the board
SPI_CS_IMU1: R13.1, U4.12 (AP_CS); also elsewhere on the board

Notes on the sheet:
Power Filter For Sensitive Electronics
Should be X7R
Primary IMU
BMP280 Barometer I2C Mode
ICM-42688-P IMU SPI Mode

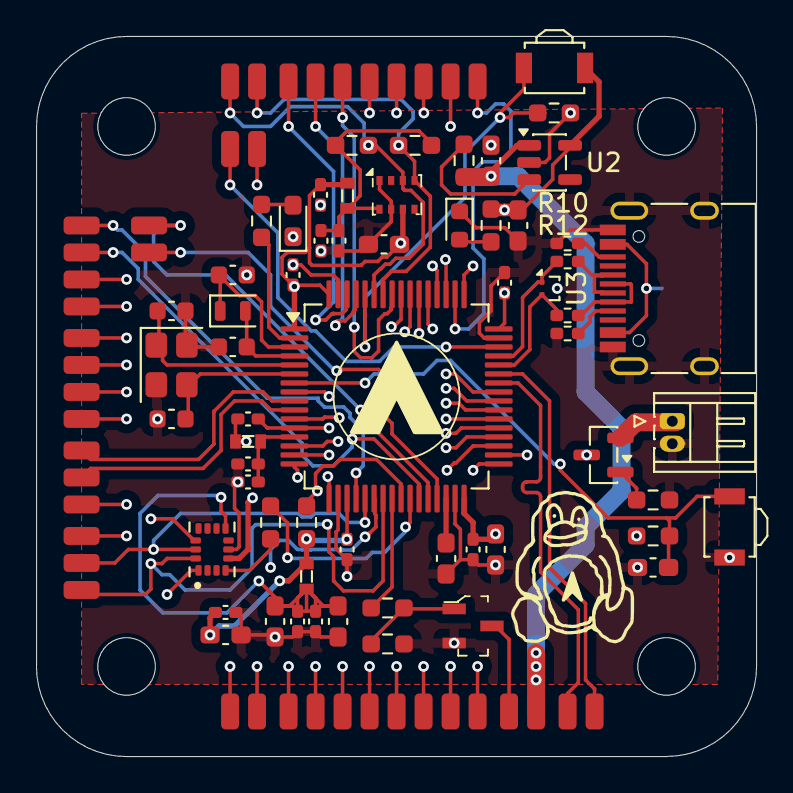
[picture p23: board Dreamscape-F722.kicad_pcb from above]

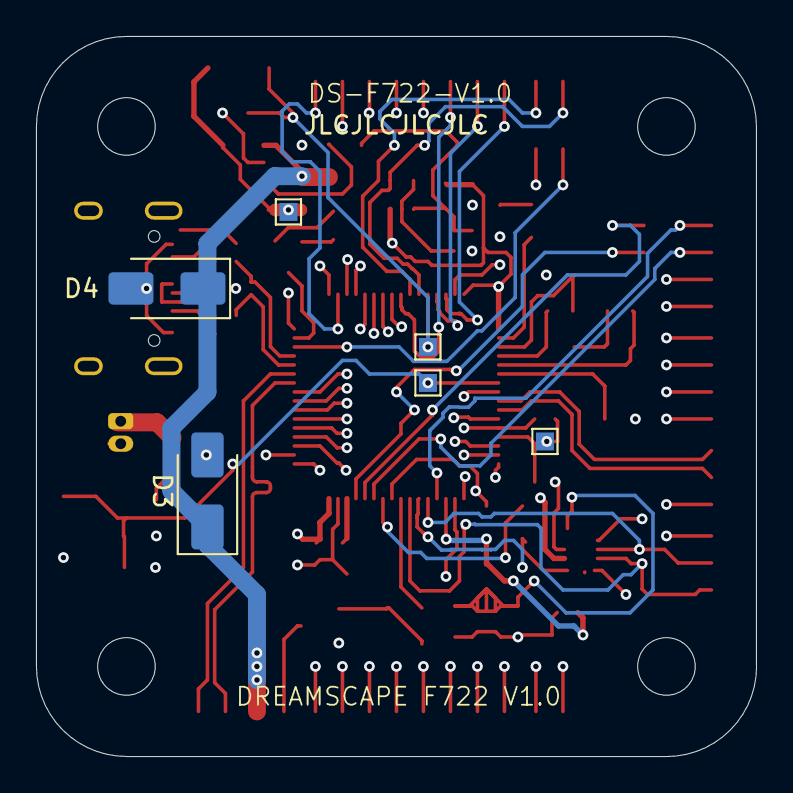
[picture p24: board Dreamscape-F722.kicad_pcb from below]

Board: 4 copper layers, 40.0 x 40.0 mm, 112 parts (6 on the bottom side), 74 nets.

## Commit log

2026-01-09 Update README with schematics and pricing images
    Added schematics, PCB views, and pricing images.
2026-01-09 optimise more
    [customDevboard.kicad_pcb]
2026-01-21 add custom parts
    [BMI270.step, DPS310.step]
2026-01-21 add bec schematic
    [bec.kicad_sch]
2026-01-21 switch to stm32
    [customDevboard.kicad_pcb, customDevboard.kicad_sch]
2026-01-24 add new part
    [FD6288Q.step]
2026-01-24 move BEC to new sheet
    [bec.kicad_sch]
2026-01-24 move sensors to new sheet
    [customDevboard_Sensors.kicad_sch]
2026-01-24 add gps module
    [gps.kicad_sch]
2026-01-24 add mosfet ao4435
    [AO4435.step]
2026-01-25 organise esc schematic
    [ESC_Motor1.kicad_sch, ESC_Motor2.kicad_sch, esc.kicad_sch]
2026-01-25 motors 3 and 4, esc
    [ESC_Motor3.kicad_sch, ESC_Motor4.kicad_sch]
2026-01-25 df13 connectors and more connectors for the bec
    [bec.kicad_sch]
2026-01-26 motor esc schematics
    [ESC_Motor1.kicad_sch, ESC_Motor2.kicad_sch, ESC_Motor3.kicad_sch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]
2026-01-27 prepare to move esc, gps, bec to other project
    [customDevboard.kicad_pcb, customDevboard.kicad_sch]
2026-01-27 BEC has been moved to its own project
    [bec.kicad_sch]
2026-01-27 GPS has been moved to its own project
    [customDevboard.kicad_pcb, gps.kicad_sch]
2026-01-29 remove bec and gps
    [customDevboard.kicad_sch]
2026-02-04 add pcb3d
2026-02-04 remove unnecessary parts
    [FD6288Q.step]
2026-02-04 remove unnecessary schematics
    [ESC_Motor1.kicad_sch, ESC_Motor2.kicad_sch, ESC_Motor3.kicad_sch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]
2026-02-04 ready for production almost
    [customDevboard.kicad_pcb, customDevboard.kicad_sch]
2026-02-04 add .blend file
    [customDevboard.blend]
2026-02-04 fix drc issues and blender render
    [customDevboard.kicad_pcb, customDevboard.kicad_sch]
2026-02-04 better blender lighting?
    [customDevboard.blend]
2026-02-05 firmware and readme
    [customDevboard.kicad_pcb, customDevboard.kicad_sch]
2026-02-05 new gerbers
2026-02-06 add switches and fix drc
    [customDevboard.kicad_pcb, customDevboard.kicad_sch]
2026-02-07 add buttons and fix drc
    [customDevboard.kicad_pcb]
2026-02-08 added ICM-42688-P IMU
    [ICM-42688-P.step]
2026-02-08 switch imu and barometer
    [customDevboard.kicad_pcb, customDevboard_Sensors.kicad_sch]
2026-02-09 restart pcb because too many new parts
    [customDevboard.kicad_pcb, customDevboard.kicad_sch, customDevboard_Sensors.kicad_sch]
2026-02-11 ready for ship
    [customDevboard.blend, customDevboard.kicad_pcb, customDevboard.kicad_sch]
2026-02-12 it came to me in a dream
    [customDevboard.kicad_pcb]
2026-02-12 add ground plane
    [customDevboard.kicad_pcb, customDevboard_Sensors.kicad_sch]
2026-02-12 beef up power traces
    [customDevboard.kicad_pcb]
2026-02-12 optimise trace placement
    [customDevboard.kicad_pcb]
2026-02-12 add Dreamscape F722 Silkscreen
    [customDevboard.kicad_pcb, customDevboard.kicad_sch]
2026-02-12 rename files
    [Dreamscape-F722.blend, Dreamscape-F722.kicad_pcb, Dreamscape-F722.kicad_sch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]
2026-02-12 build gerbers
2026-02-12 i opened the pcb file and i think it updated the dates
    [Dreamscape-F722.kicad_pcb]
2026-02-12 add 3d model
    [Dreamscape-F722.kicad_pcb]
2026-02-13 add cart images
    [Dreamscape-F722.kicad_sch, Dreamscape-F722_Sensors.kicad_sch]
2026-02-13 update blender
    [Dreamscape-F722.blend]
2026-02-13 blender updates
    [Dreamscape-F722.blend]
2026-02-17 organise files
    [Dreamscape-F722.kicad_pcb, Dreamscape-F722.kicad_sch, Dreamscape-F722.step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]
2026-02-17 optimise traces
    [Dreamscape-F722.blend, Dreamscape-F722.kicad_pcb]
2026-02-20 move imported parts into kicad directory
    [AO4435.step, BMI270.step, DPS310.step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]
2026-02-20 add diodes to pcb (wiring tomorrow)
    [Dreamscape-F722.kicad_pcb]
2026-03-05 update repos
    [Dreamscape-F722.kicad_pcb, Dreamscape-F722.kicad_sch, Unnamed.FCStd]
2026-03-06 change ldo to hand-solderable type
    [Dreamscape-F722.kicad_pcb, Dreamscape-F722.kicad_sch]
2026-03-07 update blenders
    [Dreamscape-F722.blend]
